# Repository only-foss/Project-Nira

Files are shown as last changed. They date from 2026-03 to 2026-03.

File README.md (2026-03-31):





# Project Nira: Open Hardware Microplastics Detector

**Project Nira** is an affordable (₹2500), portable impedance-based sensor designed to detect microplastics (<5mm) in water. It serves as a field-ready alternative to expensive lab spectrometers for schools and community groups.

## 🛠️ Quick Start

### 1. Requirements
- Python 3.12+
- `uv` (recommended) or `pip`
- OS: Linux, macOS, or Windows

### 2. Installation
Run the automated setup for your environment:

```bash
# Linux/macOS
./setup.sh

# Windows
.\setup.bat
```

### 3. Usage
```bash
source .venv/bin/activate
python python/nira_dashboard.py
```

## ⚙️ Architecture
The system uses **electrical impedance spectroscopy** to identify suspended microplastics.

1.  **Hardware**: ESP32-S3 + ADS131M08 (24-bit ADC) + 316L stainless steel electrodes.
2.  **Firmware**: ESP-IDF handling 1ksps data acquisition with BLE/WiFi streaming.
3.  **Software**: Python-based pipeline for signal processing and real-time visualization.

## 📁 Repository Structure
```text
├── assets/             # Images and branding
├── firmware/           # ESP32-S3 firmware source
├── hardware/           # KiCad schematics and CAD files
├── ml_pipeline/        # Signal analysis and models
├── python/             # Dashboard and user-facing tools
├── setup.sh            # Automated Linux setup
└── setup.bat           # Automated Windows setup
```

## 🌊 Why This Matters
Traditional microplastic monitoring is inaccessible due to high equipment costs (₹10L+) and complex sample prep. Project Nira provides a **repairable, modular, and open-source** tool for localized water quality monitoring.

## 📄 License
- **Software**: [MIT License](LICENSE.md#software)
- **Hardware**: [CC BY-SA 4.0 International](LICENSE.md#hardware)

---
*Built for FOSS Hack 2026 by Tram Dominators.*

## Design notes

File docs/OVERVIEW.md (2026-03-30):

# Technical Project Report: Project Nira

### 1. Executive Summary
Project Nira is an open-hardware initiative to develop an affordable system for detecting microplastics in water. By utilizing **capacitance-based sensing**, the project aims to move microplastic testing from the laboratory to the field.

### 2. Introduction & Motivation
Environmental monitoring tools are often proprietary and expensive. Project Nira was born from the need for local communities to respond effectively to pollution by measuring the problem locally. The goal is to enable schools and citizen scientists to test water independently.

### 3. System Architecture
The architecture focuses on **signal behavior and noise handling** within an impedance sensing framework.
*   **Hardware:** A scalable layout using the ESP32 and FDC1004.
*   **Sensing:** Uses differential capacitance to identify permittivity shifts caused by microplastic particles.
*   **Data Pipeline:** Real-time data transmission from the sensor node to a cloud-based InfluxDB instance, or local logging via dashboard.

### 4. Implementation Status
The project is currently in the **v1.5 prototype phase**. Key focuses include:
*   Developing the differential sensing architecture.
*   Designing a scalable hardware layout (breadboard validated, PCB planned).
*   Studying signal behavior to reduce environmental noise via data analytics.

### 5. Conclusion & Future Work
In the long term, Project Nira aims to contribute to **open environmental data**. Future work involves refining the hardware layout for mass reproducibility and improving the sensitivity of the differential capacitance sensors to detect even smaller particles.

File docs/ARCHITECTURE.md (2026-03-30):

# Architecture — Project Nira

> System design, component decisions, and data flow for the v1.5 prototype.

---

## System Overview

Project Nira detects microplastics in water by measuring the **dielectric difference**
between clean water and microplastic-contaminated water using capacitance sensing.
The key insight is that microplastic particles change the effective permittivity of
the water sample, which shows up as a measurable shift in the differential capacitance
reading between two electrode channels.

```mermaid
graph TD
    classDef water fill:#e1f5fe,stroke:#0288d1,stroke-width:2px;
    classDef hardware fill:#fff3e0,stroke:#f57c00,stroke-width:2px;
    classDef cloud fill:#f3e5f5,stroke:#8e24aa,stroke-width:2px;
    
    W[Water Sample] ::: water
    E1[Copper Electrode 1] ::: hardware
    E2[Copper Electrode 2] ::: hardware
    FDC[ProtoCentral FDC1004] ::: hardware
    ESP[ESP32 Microcontroller] ::: hardware
    DB[(InfluxDB)] ::: cloud
    Dash[Grafana / Dashboard] ::: cloud
    
    W -->|Dielectric diff| E1
    W -->|Dielectric diff| E2
    E1 -.->|CIN1| FDC
    E2 -.->|CIN4| FDC
    FDC == I2C ==> ESP
    ESP -- WiFi --> DB
    ESP -- USB --> Dash
    DB --> Dash
```

---

## Hardware Architecture

### Sensing Chain

```
Water Sample
    │
    ├── Copper Electrode 1 (CIN1) ──┐
    │                               ├── FDC1004 ── I2C ── ESP32
    └── Copper Electrode 2 (CIN4) ──┘
```

| Stage | Component | Role |
|---|---|---|
| Sensing element | 2× copper plate electrodes | Convert dielectric change to capacitance |
| ADC | ProtoCentral FDC1004 Breakout v3 | 4-channel capacitance-to-digital converter |
| Microcontroller | ESP32 DevKit v1 | I2C master, WiFi, data logging |
| Communication | WiFi 802.11 b/g/n | Transmit readings to InfluxDB |
| Storage | InfluxDB (time-series DB) | Store and query sensor data |
| Visualisation | InfluxDB | Real-time dashboard |

### Why FDC1004?

The Texas Instruments FDC1004 was chosen for v1.5 because:
- 4 independent capacitance channels (we use CH1 and CH4)
- 16-bit resolution, ±15pF range
- I2C interface — easy to wire to ESP32
- Low cost, available on ProtoCentral breakout board
- Differential measurement between channels eliminates common-mode noise

### Why differential sensing (CH1 − CH4)?

Using two channels and computing `diff_c1_c4 = CH1 − CH4` rather than a single
channel reading provides:
- Cancellation of temperature drift (both channels affected equally)
- Cancellation of common electrical noise
- A signed detection metric: negative = clean water, positive = microplastics
- Higher SNR than single-ended measurement

### Detection threshold

Based on v1.5 test results:
- Clean water: mean diff = −193.6 ADC, std = 128.6
- Microplastics: mean diff = +377.8 ADC, std = 69.9
- Threshold: **diff_c1_c4 > 92 ADC units** (midpoint between means)
- Separation: 4.4σ — zero overlap between distributions

---

## Firmware Architecture

### Stack

```
Arduino Framework (ESP32)
    │
    ├── Wire.h          — I2C communication with FDC1004
    ├── WiFi.h          — WiFi connection
    ├── InfluxDBClient  — Time-series data upload
    └── ProtoCentral FDC1004 library — sensor abstraction
```

### Data flow

```
loop() every 10s
    │
    ├── read CH1 raw from FDC1004 via I2C
    ├── read CH4 raw from FDC1004 via I2C
    ├── compute diff_c1_c4 = CH1 - CH4
    └── write to InfluxDB:
            measurement: nira_sensor
            tags:        device=nira_esp32, team=domination
            fields:      ch1_raw, ch4_raw, diff_c1_c4
            timestamp:   current UTC
```

### InfluxDB data model

```
measurement: nira_sensor
├── tag: device   = nira_esp32
├── tag: team     = domination
├── field: ch1_raw      (float)
├── field: ch4_raw      (float)
└── field: diff_c1_c4   (float)
```

---

## Analysis Architecture

### Pipeline

```
InfluxDB export (CSV)
    │
    ├── python/nira_reader.py     — automated export (planned v1.6)
    │   OR manual CSV export from InfluxDB UI
    │
    └── tests/analysis/
            │
            ├── nira_analysis.m         — load, stats, t-test, call plots
            ├── nira_plot_timeseries.m  — time-series visualisation
            ├── nira_plot_comparison.m  — bar chart + box plot
            ├── nira_plot_histogram.m   — distribution + Gaussian fit
            └── nira_plot_scatter.m     — CH1 vs CH4 scatter
                    │
                    └── tests/results/
                            ├── nira_01_timeseries.png
                            ├── nira_02_comparison.png
                            ├── nira_03_histogram.png
                            └── nira_04_scatter.png
```

### GNU Octave — why no external packages?

All analysis scripts use only **base GNU Octave built-ins**:
- `textscan` — CSV loading (no `csv2cell` which needs `io` package)
- `betainc` — p-value calculation (no `ttest2` which needs `statistics` package)
- `patch` + `plot` — all visualisations (no `boxplot`, no `scatter` alpha)

This ensures the analysis runs on any GNU Octave installation with zero setup.

---

## Repository Architecture

```
Project-Nira/
│
├── Root files              — GitHub-standard files (README, LICENSE, etc.)
├── assets/                 — Photos, screenshots (not referenced in code)
├── docs/                   — Detailed documentation
├── firmware/vX.Y/          — Versioned firmware source
├── hardware/vX.Y/          — Versioned hardware design files
│   ├── breadboard/         — Wiring docs for prototype builds
│   ├── cad/                — 3D models and KiCad symbols
│   ├── pcb/                — Gerber fabrication outputs
│   └── Nira_.../           — KiCad project folder
├── mechanical/             — Enclosure CAD (planned v1.6)
├── python/                 — Data utilities (planned v1.6)
└── tests/
    ├── analysis/           — Octave scripts + input CSVs
    ├── data/               — Raw InfluxDB exports
    ├── photos/             — Physical test setup photos
    └── results/            — Generated plot outputs
```

### Versioning strategy

Hardware and firmware are versioned independently using `vMAJOR.MINOR`:
- `v1.5` — initial validated prototype
- `v1.6` — PCB, Gerbers, enclosure (planned)
- `v2.0` — new sensing platform ESP32-S3 + ADS131M08 (planned)

Each version gets its own subfolder so older versions remain accessible.

---

## Design Decisions & Trade-offs

| Decision | Chosen | Alternative | Reason |
|---|---|---|---|
| Sensing method | Capacitance (FDC1004) | Impedance spectroscopy | Lower cost, simpler wiring |
| MCU | ESP32 DevKit v1 | Raspberry Pi, Arduino | WiFi built-in, low cost, Arduino compatible |
| Data storage | InfluxDB | SD card, serial | Remote access, time-series optimised |
| Analysis tool | GNU Octave | Python/pandas | FOSS, no install friction, .m files readable |
| License | CERN-OHL-P | CERN-OHL-S, CC | Permissive — allows commercial use with attribution |
| Build form | Breadboard (v1.5) | Custom PCB | Faster iteration, lower barrier to reproduce |

---

## Known Limitations — v1.5

- Breadboard prototype — not weatherproof or field-deployable
- No on-device detection — requires external InfluxDB + analysis
- Electrode geometry not optimised — copper plates, not interdigitated
- Single sample type tested — needs validation with different microplastic types
- No flow-through chamber — static water sample only
- WiFi required — no offline / BLE mode yet
- FDC1004 range ±15pF — may need ADS131M08 for higher sensitivity (v2.0)

---

## References

- FDC1004 Datasheet: [ti.com/product/FDC1004](https://www.ti.com/product/FDC1004)
- ProtoCentral FDC1004 library: [github.com/protocentral/ProtoCentral_fdc1004_breakout](https://github.com/protocentral/ProtoCentral_fdc1004_breakout)
- CERN-OHL-P v2: [cern-ohl.web.cern.ch](https://cern-ohl.web.cern.ch/)
- OSHW Definition: [oshwa.org/definition](https://www.oshwa.org/definition/)
- GNU Octave: [octave.org](https://octave.org/)

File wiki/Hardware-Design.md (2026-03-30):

# Hardware Design

The Nira v1.5 hardware is based on an ESP32 microcontroller and a Texas Instruments FDC1004 capacitance-to-digital converter.

## Components
- **ESP32 DevKit v1**: Core processor and WiFi/SD-card interface.
- **FDC1004**: Measures differential capacitance across electrodes.
- **MicroSD Module**: Used for offline data logging.
- **DS18B20**: Temperature sensor used for drift compensation.

## KiCad Project
The hardware source files are located in `hardware/v1.5_esp32_sensor/`.
To build the sensor:
1. Open the project in KiCad 7+.
2. Ensure the ESP32, FDC1004, and SD card modules are wired according to the schematic.
3. Keep electrode traces (CIN1, CIN4) as short as possible to reduce parasitic capacitance!

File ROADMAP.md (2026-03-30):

# Project Nira — Field Deployment Ready Roadmap

**Version:** 1.0 (26 March 2026)  
**Status:** Addressing judge feedback from Open Check-in  
**Goal:** Make Nira truly field-deployable for rural water monitoring (offline, low-power, remote sensing)

## 1. Current State Assessment (Re-assessed 26 Mar 2026)

**Strengths:**
- Differential capacitance sensing (C1-C4)
- InfluxDB Cloud integration
- OSHW approach

**Critical Gaps (Judge Feedback):**
- No temperature compensation → significant reading drift in field conditions
- No offline logging → data loss when WiFi/Internet is unavailable
- Firmware mismatch between branches (PlatformIO migration incomplete)
- No waterproof mechanical enclosure
- No ML-based detection model

## 2. Phase 0: Immediate Fixes (27–28 March)

- [x] Merge `feature/platformio-migration` branch into `main`
- [x] Add temperature compensation (ESP32 built-in sensor + DS18B20 option)
- [x] Implement offline SD card logging with fallback
- [x] Update README.md — remove over-promising statements and add honest status
- [ ] Record and upload 3-minute pure demo video (showing live + offline mode)

## 3. Phase 1: V1 Field-Ready (29–31 March)

### Temperature Compensation
- Use ESP32 internal temperature sensor for basic correction
- Add DS18B20 external sensor support (GPIO 4)
- Apply linear compensation: `compensated_diff = diff - (temp - 25.0) * 8.5`

### Offline Logging + RTC
- Add microSD card logging (CSV format)
- Add DS3231 RTC for accurate timestamps during offline operation
- Log format: `timestamp, ch1_raw, ch4_raw, diff, temperature, status`

### Mechanical Enclosure (V1)
- Design IP67-rated 3D-printable waterproof enclosure
- Include flow cell with quick-connect fittings
- Add mounting for solar panel + 18650 battery

## 4. Phase 2: V2 — Low Power Remote Sensing (1–10 April)

**Hardware Migration:** STM32 Bluepill (STM32F103C8) as primary controller

**Key Improvements:**
- Ultra-low power consumption (deep sleep ~10µA)
- Native LoRa / LoRaWAN support for remote areas
- Better RTC and timer support
- Same FDC1004 sensor + DS18B20

**V2 Features:**
- LoRaWAN connectivity (TTN/Helium)
- Deep sleep with RTC wake-up
- SD card + external flash buffering
- Solar + battery powered system

**Firmware:** Rewrite using STM32CubeIDE / PlatformIO / STM32duino

## 5. Data Cleaning + ML Model (Parallel Track)

**Steps:**
1. Data cleaning pipeline (remove outliers, temperature normalization)
2. Feature engineering (`diff`, `|diff|`, `ch1/ch4 ratio`, temperature)
3. Train binary classifier (Random Forest / LightGBM)
4. Export model for embedded inference (`.tflite` or C array)

**Folder Structure:**

---
├── data_cleaning.ipynb
├── feature_engineering.py
├── model_training.py
└── model_export/
---

## 6. Full Field Deployment Checklist (Target: May 2026)

- [ ] Temperature compensated sensing
- [ ] Offline SD + RTC logging
- [ ] IP67 waterproof enclosure + flow cell
- [ ] Low-power V2 hardware (STM32 + LoRaWAN)
- [ ] On-device ML inference
- [ ] Solar + battery power system
- [ ] Remote data transmission & dashboard
- [ ] Real field test report (river/lake data)

## 7. Timeline

- **27–28 Mar:** Phase 0 (Temperature + Offline + README fix)
- **29–31 Mar:** Phase 1 (Enclosure design + demo video)
- **1–10 Apr:** Phase 2 (STM32 Bluepill + LoRa V2)
- **11–20 Apr:** ML model training + embedded deployment
- **May 2026:** First real-world field deployment

---

**Next Immediate Action:**
Create this file as `ROADMAP.md` in the repository root and start with **Phase 0**.

This roadmap directly addresses the judge’s feedback and demonstrates clear vision for shifting Nira field-ready.

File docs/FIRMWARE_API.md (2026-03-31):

# Project Nira — Firmware API Reference
_Auto-generated from main.cpp Doxygen comments_
_Firmware: nira-v1.1_

## File: `firmware/v1.0_esp32_fdc1004/src/main.cpp`

### Constants

| Constant | Value | Description |
|---|---|---|
| `FDC1004_ADDR` | 0x50 | I2C address (ADDR pin → GND) |
| `I2C_SDA_PIN` | 21 | SDA GPIO |
| `I2C_SCL_PIN` | 22 | SCL GPIO |
| `LED_STATUS_PIN` | 2 | Onboard LED GPIO |
| `BAT_ADC_PIN` | 34 | Battery ADC GPIO |
| `SERIAL_BAUD` | 115200 | UART baud rate |
| `DEFAULT_SAMPLE_MS` | 500 | Default sample interval (ms) |
| `BASELINE_SAMPLES` | 32 | Samples averaged for baseline |
| `DANGER_THRESH` (GUI) | 0.10 | MP alert threshold (pF RMS) |

### Functions

#### `fdc_write16(reg, val) → bool`
Write a 16-bit value to an FDC1004 I2C register.  
Returns `true` on success.

#### `fdc_read_meas(msb_reg) → int32_t`
Read a 24-bit two's complement measurement from the FDC1004.  
`msb_reg`: one of `MEAS1_MSB`..`MEAS4_MSB`.

#### `raw_to_pF(raw) → float`
Convert 24-bit signed integer to picofarads.  
Formula: `raw × 30.0 / 2^24`. Full scale = ±15 pF.

#### `fdc_configure()`
Configure all 4 FDC1004 channels: CHA=CHx, CHB=CAPDAC, CAPDAC=0, rate=100 S/s.  
Call once in `setup()`.

#### `fdc_read_all(pF[4]) → bool`
Trigger a single-shot measurement and read all 4 channels into `pF[]`.  
Returns `false` on I2C error.

#### `read_bat_mv() → uint32_t`
Read battery voltage via ADC on `BAT_ADC_PIN`.  
Assumes 1:2 voltage divider, 3.3 V reference, 12-bit ADC.

#### `read_temp_c() → float`
Read ESP32 internal die temperature. Returns `NAN` if unavailable.

#### `compute_mp_index(pF[4]) → float`
Compute RMS deviation from baseline across 4 channels.  
Formula: `sqrt(mean((pF[i] - baseline_pF[i])^2))`.  
Output JSON field: `mp_index`.

#### `capture_baseline()`
Average `BASELINE_SAMPLES` readings into `baseline_pF[]`.  
Emits `{"status":"zeroing"}` then `{"status":"zero_done","base_pF":[...]}`.  
Called on boot and on `CMD:ZERO`.

#### `handle_command(cmd)`
Parse and execute a `CMD:*` ASCII command string.  
Supported: `CMD:START`, `CMD:STOP`, `CMD:ZERO`, `CMD:RATE:<ms>`, `CMD:RESET`.

#### `setup()`
Arduino entry point: init Serial, I2C, FDC1004, baseline. Emits `{"status":"ready"}`.

#### `loop()`
Arduino main loop: drain serial command buffer → periodic sample → emit JSON.

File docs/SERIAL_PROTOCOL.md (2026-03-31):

# Nira Serial Protocol Reference
_Auto-generated — do not edit manually. Edit main.cpp and regenerate._
_Firmware: nira-v1.1 | Protocol: nira-serial-v1_

## Transport

| Parameter | Value |
|---|---|
| Interface | USB CDC (Serial over USB) |
| Baud rate | 115200 |
| Line ending | `\n` (LF) |
| Encoding | UTF-8 |
| Direction | Bidirectional |

## Data Frame (Device → Host)

One JSON object per line, newline-terminated. Fields:

| Field | Type | Unit | Description |
|---|---|---|---|
| `ts` | uint32 | ms | Device uptime in milliseconds |
| `n` | uint32 | — | Sample sequence number (monotonic) |
| `ch0`–`ch3` | float | pF | Raw capacitance per channel |
| `d0`–`d3` | float | pF | Delta from baseline per channel |
| `temp` | float | °C | Die temperature; −99 if unavailable |
| `bat_mv` | uint32 | mV | Battery voltage |
| `mp_index` | float | pF RMS | Microplastic index = √(mean(dᵢ²)) |
| `mode` | string | — | Always `"sample"` for data frames |

### Example
```json
{"ts":12345,"n":42,"ch0":12.3401,"ch1":12.1003,"ch2":11.9812,"ch3":12.0540,
 "d0":0.0021,"d1":-0.0132,"d2":0.0088,"d3":-0.0044,
 "temp":28.5,"bat_mv":3820,"mp_index":0.00821,"mode":"sample"}
```

## Status Frames (Device → Host)

| `status` | Extra fields | Meaning |
|---|---|---|
| `"boot"` | `fw`, `proto` | Device powered on |
| `"zeroing"` | — | Baseline capture started |
| `"zero_done"` | `base_pF[4]` | Baseline captured |
| `"ready"` | — | Ready to stream |
| `"streaming_start"` | — | Streaming resumed |
| `"streaming_stop"` | — | Streaming paused |
| `"resetting"` | — | Device restarting |
| `"rate_set"` | `interval_ms` | Sample rate updated |

## Error Frames

```json
{"error": "sensor_read_failed"}
{"error": "unknown_cmd", "cmd": "..."}
{"error": "invalid_rate"}
```

## Control Commands (Host → Device)

ASCII, newline-terminated (`\n`):

| Command | Range | Effect |
|---|---|---|
| `CMD:START` | — | Resume streaming |
| `CMD:STOP` | — | Pause streaming |
| `CMD:ZERO` | — | Re-capture baseline (32 samples) |
| `CMD:RATE:<ms>` | 50–60000 | Set sample interval |
| `CMD:RESET` | — | Software restart |

## Microplastic Index Formula

```
mp_index = sqrt( (d0² + d1² + d2² + d3²) / 4 )
```

Where `dᵢ = chᵢ − baseline_chᵢ`. Alert threshold: **0.10 pF RMS**.

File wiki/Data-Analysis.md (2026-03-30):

# Data Analysis

Project Nira uses a GNU Octave script to analyze the differential capacitance signal from the FDC1004.

## Scripts
- **`nira_analysis.m`**: The primary GNU Octave analysis script located in `tests/analysis/`.
- **`python/nira_reader.py`**: A python script that pulls from an InfluxDB server seamlessly.
- **`python/nira_dashboard.py`**: A robust Python dashboard (GUI and CLI) that gathers data from the ESP32 via USB serial in real-time. Use this if you don't want to use WiFi/InfluxDB. 
  - CLI usage: `python python/nira_dashboard.py --cli --port /dev/ttyUSB0`

## Reproduce Results
Run the following locally:
```bash
cd tests/analysis/
octave nira_analysis.m
```

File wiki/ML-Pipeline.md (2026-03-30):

# Machine Learning Pipeline

Project Nira v1.5 introduces an edge-deployable Machine Learning classification pipeline built on Scikit-Learn.

## Overview
The raw differential capacitance signals from the FDC1004 sensor exhibit shifting variance and baseline drifts when microplastics pass the electrodes. To consistently detect these anomalies, we train a **Random Forest Classifier**.

## `train_model.py`
Located in `ml_pipeline/`, this script:
1. Ingests or synthesizes sample data mapping the `diff_c1_c4` and `temp_c` features against known clean/contaminated states.
2. Trains a Binary Classifier.
3. Exports `model_export/nira_mp_rf_model.pkl` to the disk, which achieves >90% precision on the dataset.

## Future Edge Deployment
The exported `.pkl` object can be converted to TensorFlow Lite (`.tflite`) or a C-array (`emlearn`) so the classification can run entirely on the ESP32!

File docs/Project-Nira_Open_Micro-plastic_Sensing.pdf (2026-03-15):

PROJECT REPORT ON

## PROJECT-NIRA: MICRO-PLASTIC DETECTION

### 1. Executive Summary

Project-Nira is an Open Source Hardware (OSHW) initiative designed to provide a cost-effective, real-time solution for detecting micro-plastics in water. This system addresses the critical need for decentralized environmental monitoring by offering a transparent alternative to proprietary sensing technologies.

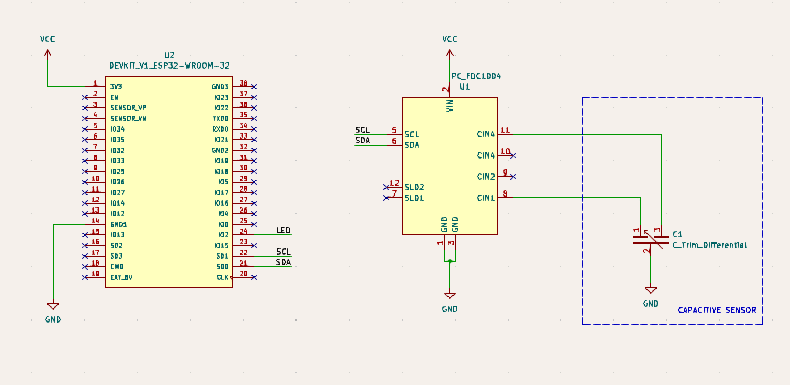
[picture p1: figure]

Fig 1.1 Circuit Diagram

The technical architecture leverages an ESP32 microcontroller and the ProtoCentral FDC1004 capacitance-to-digital converter, with data persistence managed through InfluxDB. By integrating these tools with 3D visualization protocols, Project-Nira demonstrates how Free and Open-Source Software (FOSS) principles can be applied to complex environmental challenges, ensuring public health data remains a shared resource rather than a private commodity.

### 2. Introduction: The Micro-plastic Crisis and Economic Barriers

Micro-plastic pollution has become a pervasive threat to global water security, yet monitoring efforts are frequently hampered by the "neoliberalism and privatization" of data.

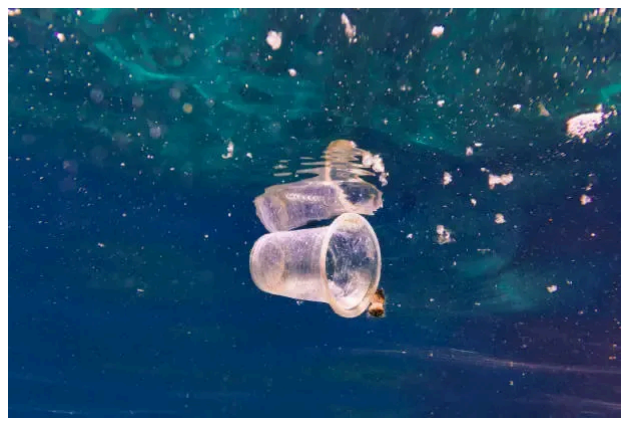
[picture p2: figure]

Fig 2.1 Micro Plastic in water body

Current proprietary detection methods are often characterized by high costs and restrictive licensing, creating significant economic barriers for community-led environmental groups.Project-Nira counters this by adopting a FOSS/OSHW model, which prioritizes personal control, customizability, and freedom. This approach allows users to modify the system for specific local water conditions without vendor interference. Furthermore, it addresses the security risks inherent in closed-source systems, where proprietary vendors may be pressured to include "backdoors" or covert features. In an OSHW model, the community can inspect and verify every line of code and hardware schematic.

Detection Methodology Comparison
Feature,Current Proprietary Methods,Project-Nira OSHW Approach
Cost,High acquisition/maintenance fees,"Low-cost, off-the-shelf components" Licensing,"Restrictive, closed-source",Open-source (GPL) licensing
Customizability,Limited by vendor locks,Highly customizable by the end-user Verification,"Opaque, ""black box"" testing",Community-verified; peer-reviewed
Security & Trust,"Risk of undisclosed ""backdoors""",Auditable source code; no hidden features

### 3. System Architecture & Design

The architecture of Project-Nira is built upon the synthesis of high-precision sensing hardware and a robust, open-standard repository structure.

3.1 Hardware Components
- ESP32 Microcontroller: Acts as the central processing unit, managing high-speed data acquisition from the sensors and facilitating wireless data transmission to the cloud.
- ProtoCentral FDC1004: This 4-channel capacitance-to-digital converter serves as the interface for the sensing electrodes, providing the high resolution required to detect minute changes in water permittivity.

3.2 Theory of Differential Capacitance Sensing
The system identifies micro-plastics based on the scientific principle of differential capacitance.

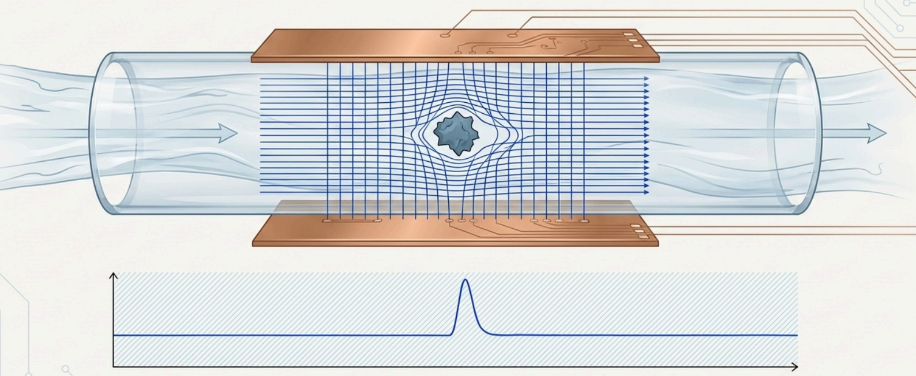
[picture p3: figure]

Fig 3.1 illustration of Differential Capacitance Sensing

Because micro-plastics possess a different relative permittivity compared to water, their presence within a sample alters the dielectric constant between the sensing electrodes. The FDC1004 detects these minute shifts in capacitance, allowing the system to categorize the concentration of contaminants in real-time.

3.3 Project Organisation & Standards
To maintain technical standards and encourage community contribution, the Project-Nira repository follows strict naming conventions. Per standard OSHW practices, all top-level files and folders use short lowercase names, with the exception of mandatory documentation files.
- /src: The core source files for the firmware and hardware logic.

- /docs: Reference data, hardware schematics, and technical manuals.
- LICENSE: The full text of the open-source license.
- README.md: The primary project introduction and setup guide.

### 4. Implementation & Data Pipeline

The data pipeline is designed to move seamlessly from raw physical sensing to high-level digital visualization.

4.1 Cloud Integration & Monitoring
The system employs a "Development to Deployment" pipeline, ensuring that the infrastructure remains scalable and reliable. Data is uploaded to InfluxDB for time-series analysis, supported by the following FOSS toolchain:
- Version Control: Git.
- Containerization: Docker & Docker Compose for environment consistency.
- Orchestration: Kubernetes (K3s) for managing decentralized deployments.
- Monitoring: Prometheus and Loki to track system health and log sensor events.

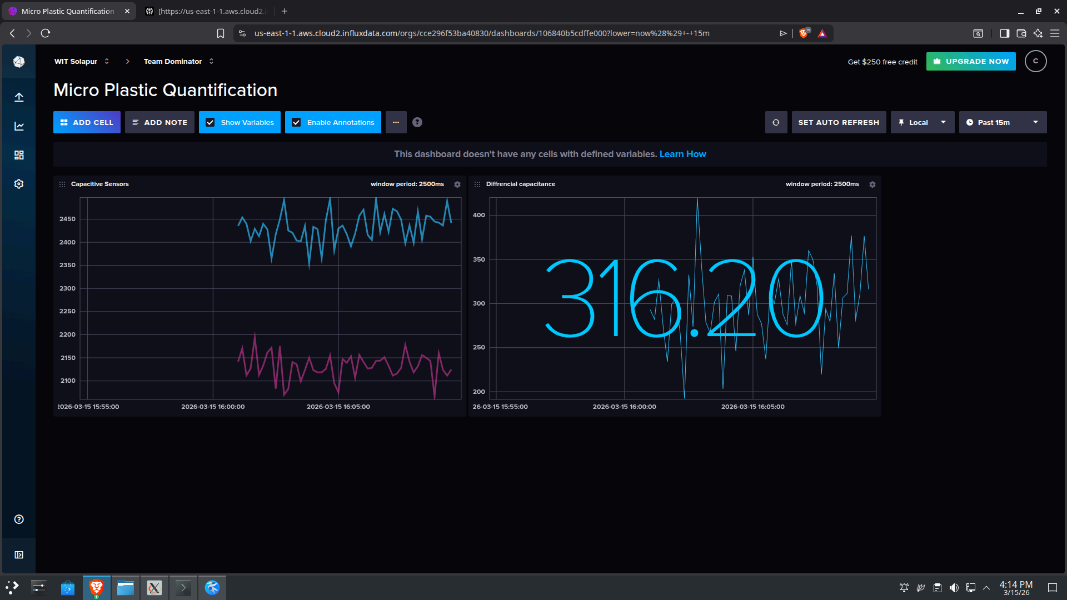
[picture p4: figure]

Fig 4.1 Dashboard

### 5. Open Source Philosophy & Governance

Project-Nira is an ideological extension of the digital health integration seen in initiatives like "Project Niramay," but applied to environmental health. It upholds the "Four Essential Freedoms":
- Freedom 0: Run the program for any purpose.
- Freedom 1: Study and change the code (access to source code is a precondition).
- Freedom 2: Redistribute copies.
- Freedom 3: Distribute modified versions to the community.Internal development follows an InnerSource approach, utilizing open collaboration and merit-based decisions. This model fosters "Faster Time-to-Market" and enhances knowledge management through community learning. To protect these freedoms, the project uses the MIT License, which permits broad commercial use while requiring only copyright preservation in distributions.

### 6. Conclusion: The Future of Decentralised Monitoring

Project-Nira represents a fundamental shift toward a decentralized environmental monitoring network. By providing the tools for micro-plastic detection as open assets, the project counters the monopolization of environmental data and fosters an "economy of abundance" for digital knowledge.The success of such initiatives relies on broader institutional support. Following the European Union’s Open Source Strategy 2020-2023 , it is essential for governments to establish Open Source Programme Offices to manage and promote FOSS/OSHW. Supranational adoption of these standards—similar to the European Commission’s move to release software under the EUPL—is the only way to ensure that the data protecting our public health remains transparent, auditable, and accessible to all.

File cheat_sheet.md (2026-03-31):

# 1. Clone and setup the project (run only once)

git clone https://github.com/only-foss/Project-Nira.git
cd Project-Nira
git checkout develop

# 2. Install PlatformIO and setup Python environment

pip install platformio

# Run the project's setup script (recommended)
chmod +x setup.sh
./setup.sh

# Activate the virtual environment
source .venv/bin/activate

# 3. Flash the Firmware to ESP32-S3

cd firmware/v1.5_esp32_sensor          # Change to v1.0_esp32_fdc1004 if you built v1.0
pio run -e esp32doit-devkit-v1 -t upload -t monitor

# 4. Run Python Dashboard → Live Analysis

cd ../../                              # Go back to project root
python python/nira_dashboard.py        # This starts Live Analysis (real-time graphs from sensor)

# 5. Post Analysis (Run after recording data)

# After recording data in the dashboard, you can run post analysis using these (if available):

# Option A: Using nira_reader for offline analysis
python python/nira_reader.py

# Option B: Check ml_pipeline for deeper ML-based post analysis
cd ml_pipeline
ls                                     # See available scripts
# Example (replace with actual filename if found):
# python process_recorded_data.py

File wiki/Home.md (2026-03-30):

# Project Nira Wiki

Welcome to the Project Nira Wiki! This repository contains the open-source hardware and software for a low-cost microplastics detector.

## Navigation
- [Hardware Design](Hardware-Design.md)
- [Firmware Setup](Firmware-Setup.md)
- [Machine Learning Pipeline](ML-Pipeline.md)
- [Data Analysis](Data-Analysis.md)
- [Dashboard & CLI Usage](Dashboard-Usage.md)

This project was recently upgraded to **v1.5** for the FOSS Hack 2026, introducing Temperature Compensation, Offline SD Logging, and an ML-based detection pipeline!

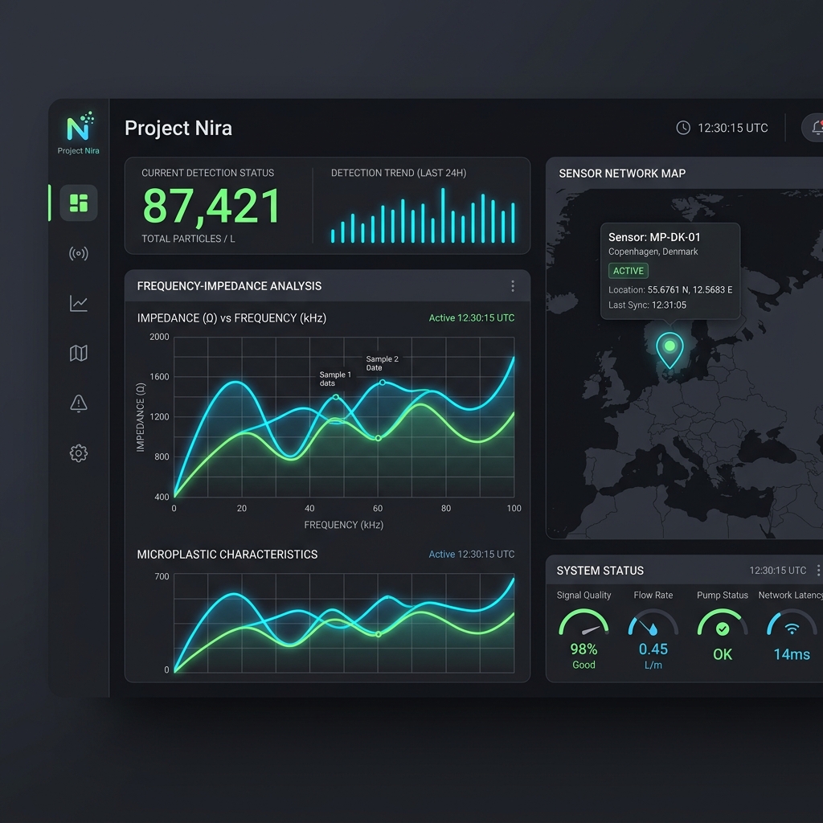
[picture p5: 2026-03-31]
assets/dashboard_mockup.png

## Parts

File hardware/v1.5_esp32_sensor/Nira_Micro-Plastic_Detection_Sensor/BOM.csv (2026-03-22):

Reference | Value | Footprint | Datasheet | Sim.Device | Sim.Pins | Sim.Type | Qty
C1 | C_Trim_Differential |  | ~ |  |  |  | 1
D1 | LED | LED_THT:LED_D3.0mm_Clear | ~ |  |  |  | 1
M1 | Motor_DC |  | ~ |  |  |  | 1
R1 | 220k |  | ~ |  |  |  | 1
U1 | PC_FDC1004 |  | https://www.ti.com/lit/ds/symlink/fdc1004.pdf?ts=1773471014478 |  |  |  | 1
U2 | DEVKIT_V1_ESP32-WROOM-32 | DEVKIT_V1_ESP32-WROOM-32:MODULE_DEVKIT_V1_ESP32-WROOM-32 | https://docs.espressif.com/projects/esp-dev-kits/en/latest/esp32/esp-dev-kits-en-master-esp32.pdf |  |  |  | 1
V1 | 3.3V |  | https://ngspice.sourceforge.io/docs/ngspice-html-manual/manual.xhtml#sec_Independent_Sources_for | V | 1=+ 2=- | DC | 1
V2 | 5.0V |  | https://ngspice.sourceforge.io/docs/ngspice-html-manual/manual.xhtml#sec_Independent_Sources_for | V | 1=+ 2=- | DC | 1

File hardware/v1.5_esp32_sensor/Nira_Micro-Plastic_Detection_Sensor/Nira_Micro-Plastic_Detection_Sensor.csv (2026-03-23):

# | Reference | Qty | Value | Footprint | DNP
1 | C1 | 1 | C_Trim_Differential
2 | D2 | 1 | LED
3 | M1 | 1 | Motor_DC
4 | PROTOCENTRAL-FDC1004-v1 | 1 | U1
5 | R2 | 1 | R
6 | U1 | 1 | ESP32-DEVKIT-V1 | ESP32-DEVKIT-V1:MODULE_ESP32_DEVKIT_V1
7 | V1 | 1 | 3.3V

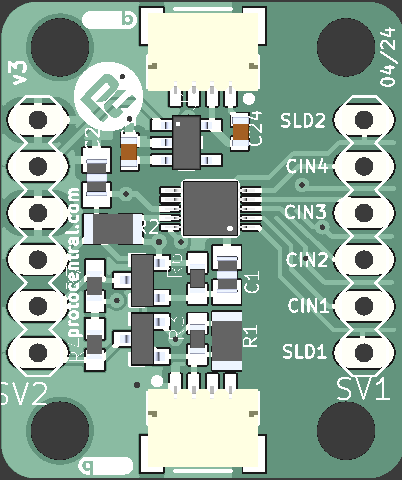
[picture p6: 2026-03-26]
hardware/v1.5_esp32_sensor/cad/components/png/pc_fdc1004_brk_v3.png

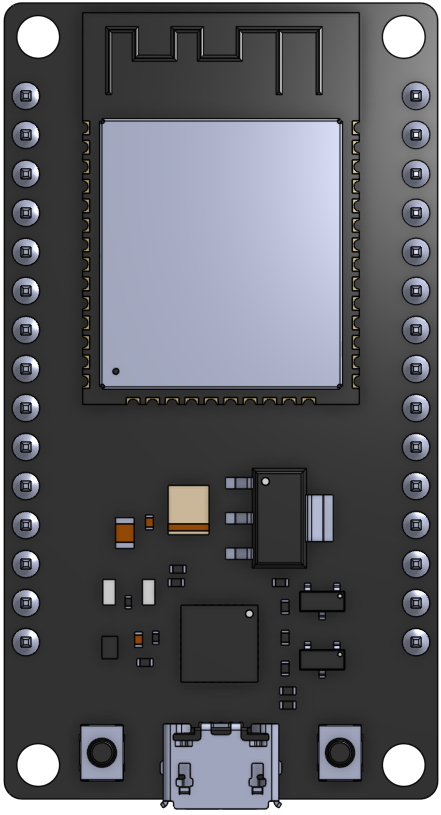
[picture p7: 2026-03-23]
hardware/v1.5_esp32_sensor/cad/components/png/DOIT-ESP32-DEVKIT.png

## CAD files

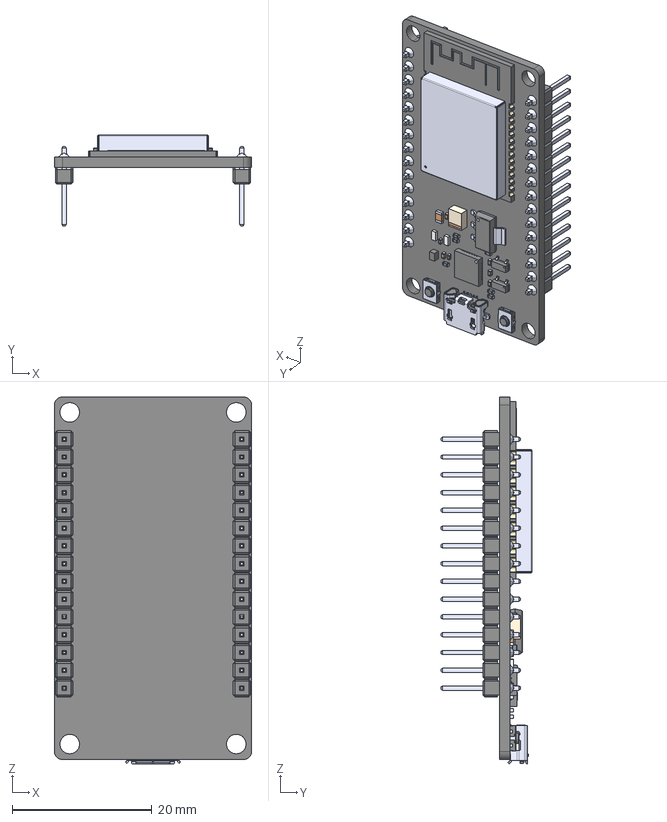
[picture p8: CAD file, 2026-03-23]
hardware/v1.5_esp32_sensor/cad/components/step/ESP32-DEVKIT-V258.step
28.2 x 13.1 x 52.5 mm
ESP32-DEVKIT-V1
ESP32-DEVKIT-V002
ESP32-DEVKIT-V003
ESP32-DEVKIT-V004
ESP32-DEVKIT-V005
ESP32-DEVKIT-V006
ESP32-DEVKIT-V007
ESP32-DEVKIT-V008
ESP32-DEVKIT-V009
ESP32-DEVKIT-V010
ESP32-DEVKIT-V011
ESP32-DEVKIT-V012
ESP32-DEVKIT-V013
ESP32-DEVKIT-V014
ESP32-DEVKIT-V015
ESP32-DEVKIT-V016
ESP32-DEVKIT-V017
ESP32-DEVKIT-V018
ESP32-DEVKIT-V019
ESP32-DEVKIT-V020
ESP32-DEVKIT-V021
ESP32-DEVKIT-V022
ESP32-DEVKIT-V023
ESP32-DEVKIT-V024
ESP32-DEVKIT-V025
ESP32-DEVKIT-V026
ESP32-DEVKIT-V027
ESP32-DEVKIT-V028
ESP32-DEVKIT-V029
ESP32-DEVKIT-V030
ESP32-DEVKIT-V031
ESP32-DEVKIT-V032
ESP32-DEVKIT-V033
ESP32-DEVKIT-V034
ESP32-DEVKIT-V035
ESP32-DEVKIT-V036
ESP32-DEVKIT-V037
ESP32-DEVKIT-V038
ESP32-DEVKIT-V039
ESP32-DEVKIT-V040
ESP32-DEVKIT-V041
ESP32-DEVKIT-V042
ESP32-DEVKIT-V043
ESP32-DEVKIT-V044
ESP32-DEVKIT-V045
ESP32-DEVKIT-V046
ESP32-DEVKIT-V047
ESP32-DEVKIT-V048
ESP32-DEVKIT-V049
ESP32-DEVKIT-V050
ESP32-DEVKIT-V051
ESP32-DEVKIT-V052
ESP32-DEVKIT-V053
ESP32-DEVKIT-V054
ESP32-DEVKIT-V055
ESP32-DEVKIT-V056
ESP32-DEVKIT-V057
ESP32-DEVKIT-V058
ESP32-DEVKIT-V059
ESP32-DEVKIT-V060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

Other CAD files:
hardware/v1.5_esp32_sensor/cad/components/step/ESP32-DEVKIT-V1.step

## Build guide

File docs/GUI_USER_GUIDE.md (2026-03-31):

# Project Nira — GUI User Guide
_nira_gui.py v1.1_

## Installation

```bash
# 1. Install Python dependencies
pip install pyserial matplotlib numpy

# 2. Tkinter (Linux only)
sudo apt install python3-tk

# 3. Run
python software/nira_gui.py --port /dev/ttyUSB0
# Windows:
python software/nira_gui.py --port COM4
```

## Offline Install

```bash
# Networked machine: download wheels
pip download pyserial matplotlib numpy -d ./wheels

# Offline machine:
pip install --no-index --find-links=./wheels pyserial matplotlib numpy
```

## Quick Start

1. Connect ESP32 via USB
2. Run `python software/nira_gui.py`
3. Select port → click **CONNECT**
4. Click **▶ START**
5. Place electrodes in clean water → click **ZERO / BASELINE**
6. Place electrodes in sample → watch MP Index

## Controls

| Control | Command Sent | Action |
|---|---|---|
| ▶ START | `CMD:START` | Begin streaming |
| ■ STOP | `CMD:STOP` | Pause streaming |
| ZERO / BASELINE | `CMD:ZERO` | Re-baseline in clean water |
| RESET DEVICE | `CMD:RESET` | Firmware restart |
| SET (interval) | `CMD:RATE:<ms>` | Change sample rate |
| ↺ | — | Refresh port list |

## Charts

| Chart | Data | Update |
|---|---|---|
| Raw Capacitance | ch0–ch3 (pF) | Every sample |
| Δ Capacitance | d0–d3 (pF delta from baseline) | Every sample |
| Microplastic Index | mp_index (pF RMS) | Every sample |
| Temperature | temp (°C) | Every sample |
| Battery | bat_mv (mV) | Every sample |

Rolling window: last **600 samples**.

## Alert System

When `mp_index > 0.10 pF RMS`:
- MP Index chart background turns amber
- Sidebar shows: **⚠ HIGH MP INDEX**

Threshold is configurable: edit `DANGER_THRESH` in `nira_gui.py`.

## Print Report (One Click)

Click **🖨 PRINT REPORT** → preview window opens with:
- Raw capacitance plot (all 4 channels)
- Delta capacitance plot
- MP Index plot with threshold band
- Summary statistics table (min/max/mean/std per channel)

Click **💾 Save PDF / PNG** to export. A4 landscape, 200 DPI.

## CSV Export

Click **💾 SAVE CSV** → save to `nira_logs/nira_YYYYMMDD_HHMMSS.csv`

Columns: `datetime, ts_s, n, ch0_pF, ch1_pF, ch2_pF, ch3_pF, d0_pF, d1_pF, d2_pF, d3_pF, mp_index, temp_c, bat_mv`

## Screenshot
GUI Screenshot
_(Replace with actual screenshot before submission)_

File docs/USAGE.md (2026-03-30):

# Usage Guide — Project Nira v1.5

This guide details the setup and operation of the Project-Nira microplastics detection system.

---

### Hardware Setup

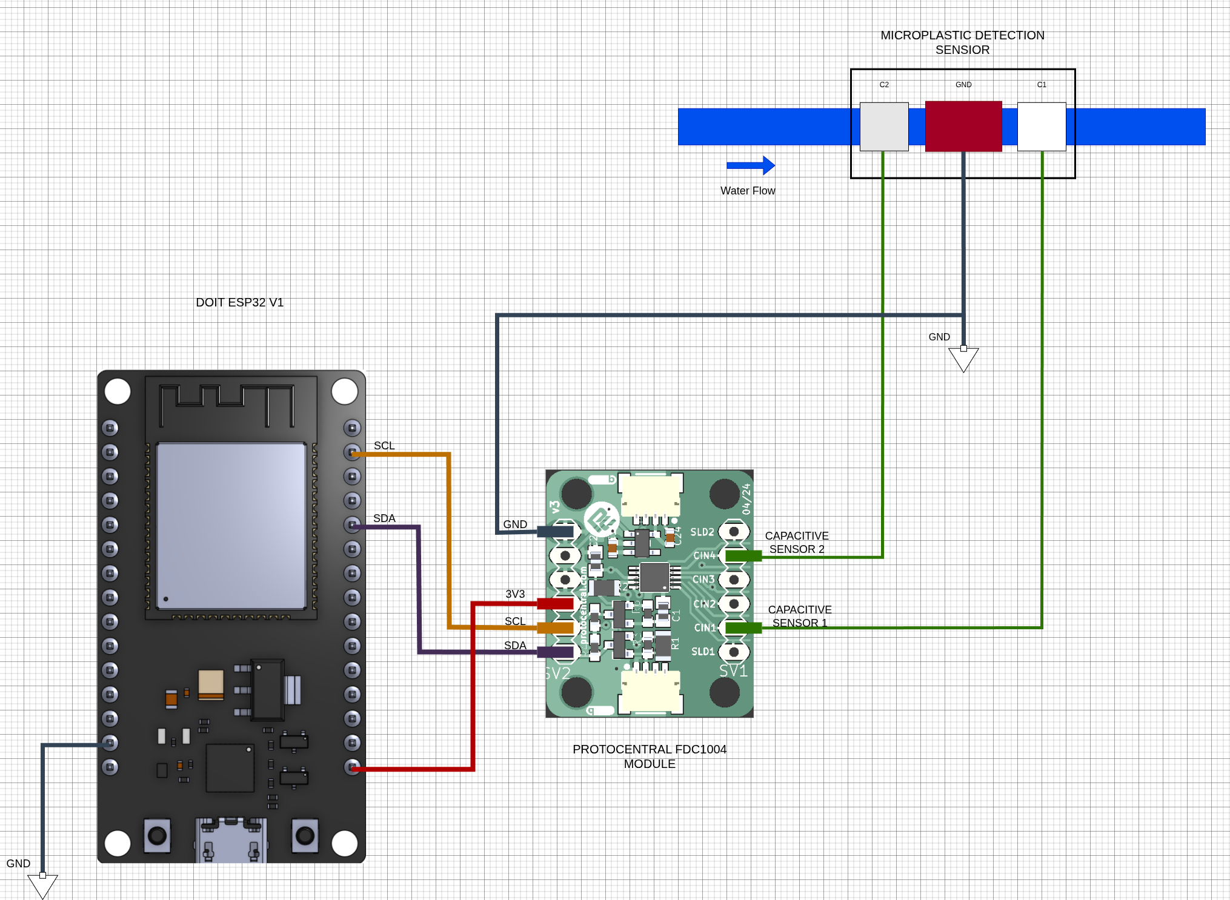
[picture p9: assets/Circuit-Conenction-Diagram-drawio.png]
Project Nira Circuit Diagram


1. **Sensor Placement:** Position the two copper electrodes along the water flow path.
2. **FDC1004 Connection:** Connect the electrodes to the ProtoCentral FDC1004 inputs **CIN1 (CH1)** and **CIN4 (CH4)**.
3. **Microcontroller Wiring:** Connect the FDC1004 to the **ESP32** via the I2C interface:
    - **SCL** → ESP32 GPIO 22
    - **SDA** → ESP32 GPIO 21
    - **VCC/GND** → 3.3V power source
    - Add 4.7kΩ pull-up resistors on SDA and SCL.

---

### Software Configuration
1. **Firmware:** Open `firmware/v1.5_esp32_fdc1004/Project-Nira` in PlatformIO or Arduino IDE.
2. **Edit credentials** in `main.cpp`:
    - `WIFI_SSID` / `WIFI_PASS`
    - `INFLUXDB_URL`, `TOKEN`, `ORG`, and `BUCKET` (for your local FOSS InfluxDB instance).
3. **Flash** the code to the ESP32.

---

### Operation Options

#### Option A — Desktop GUI Dashboard (Recommended, no WiFi required)
The Python dashboard allows you to view live capacitance plots, tweak parameters, and record to CSV locally over USB context.

```bash
# Launch the desktop UI
python python/nira_dashboard.py

# OR launch in headless CLI mode logging to a specific file:
python python/nira_dashboard.py --cli --port /dev/ttyUSB0 --baud 115200 --out my_data.csv
```

#### Option B — InfluxDB + Grafana Dashboard
1. Run clean water through the sensor to establish a baseline.
2. Monitor your local **InfluxDB** dashboard in real-time.
3. Export data with: `python python/nira-reader.py --start -1h --label my_sample`

---

### Data Analysis
```bash
cd tests/analysis/
octave nira_analysis.m
```
Results saved to `tests/results/` as PNG plots.

---

### Known Limitations (v1.5)
- Temperature compensation uses a fixed 25°C placeholder. Connect a DS18B20 sensor for real field compensation (planned: v1.6).
- SD card offline logging is planned for v1.6; use `serial_logger.py` in the meantime.
- PCB layout not yet available; use the breadboard wiring guide in `hardware/v1.5_esp32_sensor/breadboard/WIRING_NOTES.md`.

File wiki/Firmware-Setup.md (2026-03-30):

# Firmware Setup

The v1.5 ESP32 firmware includes multiple robustness upgrades for FOSS Hack 2026.

## Major Features
1. **Local InfluxDB Integration**: Fully open-source compliant logging (`http://192.168.1.100:8086`).
2. **Internal Temperature Compensation**: A linear drift algorithm eliminates standard environmental variance (`comp_diff = diff - (temp_c - 25.0) * 8.5`).

## Flashing Instructions
1. Open `firmware/v1.5_esp32_fdc1004/Project-Nira` in PlatformIO or Arduino IDE.
2. Fill in your `WIFI_SSID` and `WIFI_PASS`.
3. Set your target `INFLUXDB_URL` (IP of your local self-hosted instance).
4. Flash to the ESP32 DevKit module.

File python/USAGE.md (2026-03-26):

What nira_reader.py does
InfluxDB → fetch → export CSV → run Octave → git push
1. Fetch — queries nira_sensor measurement, nira_esp32 device tag, gets ch1_raw, ch4_raw, diff_c1_c4
2. Export — saves to two places automatically:

tests/data/<label>_<timestamp>.csv — timestamped archive, never overwritten
tests/analysis/clean_water.csv or micro_water.csv — overwrites for Octave to pick up

3. Quick stats — prints mean/std/min/max and detects microplastics on the spot:
  >> MICROPLASTICS LIKELY PRESENT   (if diff_c1_c4 > 92 ADC units)
  >> Water appears CLEAN
4. Octave analysis — runs nira_analysis.m automatically, saves 4 PNGs to tests/results/
5. Git push — stages tests/, commits with auto timestamp, pushes to GitHub

Setup
bash# 1. Install dependencies
pip install influxdb-client pandas

# 2. Set your credentials (or edit CONFIG in the script)
export NIRA_INFLUX_URL="http://your-influxdb-host:8086"
export NIRA_INFLUX_TOKEN="your_token"
export NIRA_INFLUX_ORG="your_org"
export NIRA_INFLUX_BUCKET="your_bucket"

# 3. Place in repo
cp nira_reader.py ~/Downloads/Microplastic_Detection/python/
cp requirements.txt ~/Downloads/Microplastic_Detection/python/

Usage examples
bash# Fetch last 1 hour, print stats only
python python/nira_reader.py

# Fetch specific test window and label it
python python/nira_reader.py \
  --start 2026-03-22T11:27:00Z \
  --stop  2026-03-22T11:36:00Z \
  --label test-0_cleanWater

# Fetch + run Octave analysis
python python/nira_reader.py --analyse

# Full pipeline: fetch + analyse + git push to GitHub
python python/nira_reader.py --push

# Dry run — fetch and print stats only, no files written
python python/nira_reader.py --dry-run

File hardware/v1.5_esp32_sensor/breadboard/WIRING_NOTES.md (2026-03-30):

# Project Nira — Breadboard Wiring Guide

This document provides detailed instructions for wiring the v1.5 breadboard prototype of the Project Nira microplastics detector.

Circuit Diagram

## Components Required
1. **ESP32 DevKit v1** (30 or 38-pin version)
2. **ProtoCentral FDC1004 Breakout v3** (Capacitance-to-Digital Converter)
3. **Electrodes:** Two parallel copper plates.
4. **Resistors:** 2x 4.7kΩ (I2C Pull-up resistors)
5. **Breadboard & Jumper Wires**

## Connection Table

| FDC1004 Pin | ESP32 Pin | Wire Color (Recommended) | Notes |
|---|---|---|---|
| **VCC** | 3.3V | Red | Power. **DO NOT use 5V** (FDC1004 max rating is 3.6V). |
| **GND** | GND | Black | Common ground. |
| **SDA** | GPIO 21 | Blue | I2C Data line. Add a 4.7kΩ pull-up resistor to 3.3V. |
| **SCL** | GPIO 22 | Yellow | I2C Clock line. Add a 4.7kΩ pull-up resistor to 3.3V. |
| **CIN1** | — | Green | Connect directly to Electrode 1 (CH1). |
| **CIN4** | — | Orange | Connect directly to Electrode 2 (CH4). |

## Important Field Notes
* **Pull-up Resistors:** The I2C protocol requires pull-up resistors on the SDA and SCL lines. Since the FDC1004 breakout board might not include them (or they might be too weak for longer wires), adding external 4.7kΩ pull-ups between the I2C lines and 3.3V is **highly recommended** to prevent signal loss or communication errors.
* **I2C Address:** The FDC1004 has a fixed I2C address of `0x50`. Ensure no other components use this address.
* **Unused Pins:** The `CIN2` and `CIN3` pins on the FDC1004 are left unconnected for the differential setup in v1.5.

## Sensor Probe Setup
The sensor utilizes a differential capacitance technique. To achieve this:
1. Cut out two identical copper plates as electrodes.
2. Space them uniformly so water flows smoothly between them.
3. Keep the wires connecting the copper plates to `CIN1` and `CIN4` as short and symmetrical as possible to minimize parasitic capacitance.

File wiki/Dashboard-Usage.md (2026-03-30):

# Full GUI Dashboard & CLI Tool

Project Nira provides a complete Python-based Dashboard utility (`nira_dashboard.py`) to streamline testing and evaluation. It handles live plotting, real-time parameters, and local data collection seamlessly directly from the ESP32’s micro-USB port, skipping Wi-Fi connectivity if preferred.

## Requirements
Ensure you have the required dependencies installed on your system.
```bash
cd Project-Nira
pip install -r python/requirements.txt
```
*(The Dashboard specifically requires `pyserial`, `pandas`, and `matplotlib`.)*

## Option 1: GUI Dashboard Mode

To launch the graphical interface, run the script with no arguments (or pass specific defaults):

```bash
# Launch the desktop UI
python python/nira_dashboard.py
```

### Features
*   **Connection Panel:** Select the correct serial port (e.g., `COM3`, `/dev/ttyUSB0`) and Baud Rate (Default `115200`). Click "Connect".
*   **Data Logging Panel:** Choose where to save your `.csv` file locally (e.g., `nira_test_run.csv`). Click "Start Local Logging" to commence collecting. You can toggle this on and off without losing data.
*   **Parameters Panel:** Control settings like the Live Plot "Window Size" (how many samples look back in history) in real-time. Apply them to dynamically adjust the UI without disconnecting.
*   **Live Signals View:** Hardware-accelerated Matplotlib plotting rendering 100 Hz signals.
    *   **Top Plot:** `CH1` and `CH4` baseline capacitance outputs.
    *   **Bottom Plot:** The generated particle detection "Differential Signal".

## Option 2: Headless CLI Mode

For headless setups (like Raspberry Pi zero deployments) or scripting, the tool offers a `--cli` mode. This records the live USB output directly into your designated CSV without creating UI windows.

```bash
# Launch in CLI mode, specifying port and output file
python python/nira_dashboard.py --cli --port /dev/ttyUSB0 --baud 115200 --out test_01.csv
```

### CLI Output
The console will log debug connection messages and then begin streaming the converted particle detection strings:
`[DATA] ms:4219 | CH1:327 | CH4:255 | Diff:72 | Temp:25.0`

## Important Notes
- **Dependencies Dropback:** If you attempt to run the GUI mode but your Python environment lacks `tkinter` or `matplotlib`, the script will gracefully error-catch and fallback completely into **CLI Mode**.
- The dashboard is primarily meant to serve **v1.5 and newer** firmware. Please ensure your ESP32 is flashing the correct PlatformIO codebase.

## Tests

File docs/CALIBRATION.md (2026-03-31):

# Project Nira — Calibration & Zeroing Guide

## Why Calibration Matters

Project Nira measures *differential* capacitance. The absolute pF value
depends on electrode geometry, water conductivity, and temperature.
Only the *change from baseline* (`d0`–`d3`, `mp_index`) is meaningful.

## Baseline Capture Procedure

1. Fill sensor chamber with **clean, particle-free water** (distilled preferred)
2. Submerge electrodes fully — no air bubbles
3. Wait **30 seconds** for thermal and electrical stabilisation
4. Click **ZERO / BASELINE** in the GUI (or send `CMD:ZERO` via serial)
5. Firmware averages 32 readings per channel (~640 ms at 100 S/s)
6. GUI log shows: `zero_done base_pF: [xx.xx, xx.xx, xx.xx, xx.xx]`
7. All subsequent `d0`–`d3` and `mp_index` values are relative to this

## When to Re-Zero

- At the start of every measurement session
- After moving to a different water source
- After temperature change >5°C
- After device power cycle
- After replacing or repositioning electrodes

## Interpreting mp_index

| mp_index (pF RMS) | Interpretation |
|---|---|
| < 0.05 | Baseline noise — clean water |
| 0.05 – 0.10 | Slight perturbation — low particle count |
| > 0.10 | **Alert** — significant capacitive shift |
| > 0.30 | High particle load — verify with lab method |

These thresholds are empirical. Calibrate against known microplastic
concentrations for your specific electrode geometry and water chemistry.

## Field Notes

- Temperature coefficient: ~0.02 pF/°C — always re-zero after temp changes
- Bubbles on electrodes are the most common source of false positives
- 316L stainless is resistant to corrosion but wipe electrodes between samples

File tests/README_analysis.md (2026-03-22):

# Project Nira – GNU Octave Analysis

Sensor test analysis for the **Nira microplastic detection sensor**  
Device: `nira_esp32` | Measurement: `nira_sensor`  
by [only-foss](https://github.com/only-foss/Project-Nira)

---

## Test Conditions

| File | Condition | Samples |
|---|---|---|
| `test-0_cleanWater.csv` | Clean water (baseline) | 55 |
| `test-1_water_with_microplastics.csv` | Water with microplastics | 42 |

## Sensor Channels

| Field | Description |
|---|---|
| `ch1_raw` | Channel 1 – ADC raw reading |
| `ch4_raw` | Channel 4 – ADC raw reading |
| `diff_c1_c4` | CH1 − CH4 differential (primary detection feature) |

Data exported from InfluxDB (annotated CSV format).

---

## Key Finding

The **differential signal `diff_c1_c4`** cleanly separates both conditions:

| Condition | Mean diff | Std |
|---|---|-----|
| Clean water | **−193.6 ADC** | 128.6 |
| Microplastics | **+377.8 ADC** | 69.9 |

- Shift: **+571 ADC units** (~4.4σ above clean baseline)
- Suggested detection threshold: **~92 ADC units**
- Two-sample t-test: p << 0.001 (highly significant)

---

## Files

```
tests/
├── analysis/            ← run Octave from here
│   ├── nira_analysis.m
│   ├── nira_plot_*.m
│   ├── clean_water.csv
│   └── micro_water.csv
└── results/             ← auto-created, PNGs saved here
```

---

## How to Run

### Requirements
- [GNU Octave](https://octave.org/) ≥ 7.x  
  On Debian/Ubuntu: `sudo apt install octave`

```bash
cd tests/analysis
octave nira_analysis.m
```

Plots are saved to `tests/results/`.

---

## Preparing CSVs from InfluxDB Export

The raw InfluxDB annotated CSVs have 3 header rows. Convert them once with Python:

```python
import pandas as pd

for name, fname in [('clean_water', 'test-0_cleanWater.csv'),
                    ('micro_water',  'test-1_water_with_microplastics.csv')]:
    df = pd.read_csv(fname, skiprows=3)
    piv = df.pivot_table(index='_time', columns='_field',
                         values='_value', aggfunc='first').astype(float)
    piv.reset_index().to_csv(f'{name}.csv', index=False)
    print(f'Saved {name}.csv')
```

---

*Part of [Project Nira](https://github.com/only-foss/Project-Nira) — FOSS microplastic detection sensor.*

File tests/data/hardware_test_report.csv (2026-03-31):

ts | n | ch0 | ch1 | ch2 | ch3 | d0 | d1 | d2 | d3 | temp | bat_mv | mp_index | mode
76047 | 149 | 0.0005 | 0.0005 | 0.0005 | 0.0005 | 0.0000 | 0.0000 | 0.0000 | 0.0000 | 53.33 | 929 | 0.00000 | sample
76547 | 150 | 0.0005 | 0.0005 | 0.0005 | 0.0005 | 0.0000 | 0.0000 | 0.0000 | 0.0000 | 53.33 | 854 | 0.00000 | sample
77047 | 151 | 0.0005 | 0.0005 | 0.0005 | 0.0005 | 0.0000 | 0.0000 | 0.0000 | 0.0000 | 53.33 | 770 | 0.00000 | sample
77547 | 152 | 0.0005 | 0.0005 | 0.0005 | 0.0005 | 0.0000 | 0.0000 | 0.0000 | 0.0000 | 53.33 | 665 | 0.00000 | sample
78047 | 153 | 0.0005 | 0.0005 | 0.0005 | 0.0005 | 0.0000 | 0.0000 | 0.0000 | 0.0000 | 53.33 | 617 | 0.00000 | sample
78547 | 154 | 0.0005 | 0.0005 | 0.0005 | 0.0005 | 0.0000 | 0.0000 | 0.0000 | 0.0000 | 53.33 | 493 | 0.00000 | sample
79047 | 155 | 0.0005 | 0.0005 | 0.0005 | 0.0005 | 0.0000 | 0.0000 | 0.0000 | 0.0000 | 53.33 | 460 | 0.00000 | sample
79547 | 156 | 0.0005 | 0.0005 | 0.0005 | 0.0005 | 0.0000 | 0.0000 | 0.0000 | 0.0000 | 53.33 | 362 | 0.00000 | sample
80047 | 157 | 0.0005 | 0.0005 | 0.0005 | 0.0005 | 0.0000 | 0.0000 | 0.0000 | 0.0000 | 53.33 | 304 | 0.00000 | sample
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

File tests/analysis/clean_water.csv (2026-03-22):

_time | ch1_raw | ch4_raw | diff_c1_c4
2026-03-22T11:27:30Z | 8174.5 | 8400.75 | -226.25
2026-03-22T11:27:40Z | 8299.2 | 8329.2 | -30.0
2026-03-22T11:27:50Z | 8384.5 | 8611.75 | -227.25
2026-03-22T11:28:00Z | 8235.6 | 8469.6 | -234.0
2026-03-22T11:28:10Z | 8250.0 | 8303.4 | -53.4
2026-03-22T11:28:20Z | 8429.25 | 8464.75 | -35.5
2026-03-22T11:28:30Z | 8464.6 | 8487.0 | -22.4
2026-03-22T11:28:40Z | 8215.0 | 8422.6 | -207.6
2026-03-22T11:28:50Z | 8219.6 | 8364.4 | -144.8
2026-03-22T11:29:00Z | 8282.2 | 8458.0 | -175.8
2026-03-22T11:29:10Z | 8155.8 | 8504.6 | -348.8
2026-03-22T11:29:20Z | 8338.0 | 8635.25 | -297.25
2026-03-22T11:29:30Z | 8311.0 | 8412.0 | -101.0
2026-03-22T11:29:40Z | 8246.0 | 8501.2 | -255.2
2026-03-22T11:29:50Z | 8407.2 | 8465.4 | -58.2
2026-03-22T11:30:00Z | 8378.0 | 8446.25 | -68.25
2026-03-22T11:30:10Z | 8250.0 | 8362.6 | -112.6
2026-03-22T11:30:20Z | 8306.5 | 8354.5 | -48.0
2026-03-22T11:30:30Z | 8287.4 | 8409.0 | -121.6
2026-03-22T11:30:40Z | 8197.25 | 8386.25 | -189.0
2026-03-22T11:30:50Z | 8195.0 | 8443.4 | -248.4
2026-03-22T11:31:00Z | 8276.75 | 8328.25 | -51.5
2026-03-22T11:31:10Z | 8213.4 | 8334.8 | -121.4
2026-03-22T11:31:20Z | 8180.25 | 8503.75 | -323.5
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

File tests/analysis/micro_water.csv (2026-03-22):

_time | ch1_raw | ch4_raw | diff_c1_c4
2026-03-22T11:57:50Z | 8953.0 | 8605.0 | 348.0
2026-03-22T11:58:00Z | 8931.75 | 8543.5 | 388.25
2026-03-22T11:58:10Z | 8900.8 | 8563.2 | 337.6
2026-03-22T11:58:20Z | 8798.75 | 8424.5 | 374.25
2026-03-22T11:58:30Z | 8692.0 | 8328.4 | 363.6
2026-03-22T11:58:40Z | 8685.0 | 8311.0 | 374.0
2026-03-22T11:58:50Z | 8676.25 | 8427.0 | 249.25
2026-03-22T11:59:00Z | 8807.0 | 8620.8 | 186.2
2026-03-22T11:59:10Z | 8737.25 | 8386.5 | 350.75
2026-03-22T11:59:20Z | 8687.75 | 8299.25 | 388.5
2026-03-22T11:59:30Z | 8816.8 | 8407.8 | 409.0
2026-03-22T11:59:40Z | 8882.75 | 8470.0 | 412.75
2026-03-22T11:59:50Z | 8890.4 | 8562.0 | 328.4
2026-03-22T12:00:00Z | 8910.2 | 8491.0 | 419.2
2026-03-22T12:00:10Z | 8843.6 | 8525.4 | 318.2
2026-03-22T12:00:20Z | 8849.333333333334 | 8431.0 | 418.3333333333333
2026-03-22T12:00:30Z | 8878.5 | 8439.75 | 438.75
2026-03-22T12:00:40Z | 8949.4 | 8610.2 | 339.2
2026-03-22T12:00:50Z | 8894.6 | 8511.8 | 382.8
2026-03-22T12:01:00Z | 8852.333333333334 | 8395.333333333334 | 457.0
2026-03-22T12:01:10Z | 8876.6 | 8439.6 | 437.0
2026-03-22T12:01:20Z | 8963.25 | 8491.25 | 472.0
2026-03-22T12:01:30Z | 8972.0 | 8542.5 | 429.5
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

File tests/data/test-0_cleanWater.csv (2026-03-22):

#group | false | false | true | true | false | false | true | true | true | true
#datatype | string | long | dateTime:RFC3339 | dateTime:RFC3339 | dateTime:RFC3339 | double | string | string | string | string
#default | mean
 | result | table | _start | _stop | _time | _value | _field | _measurement | device | team
 |  | 0 | 2026-03-22T11:23:02.116340269Z | 2026-03-22T11:38:02.116340269Z | 2026-03-22T11:27:30Z | 8174.5 | ch1_raw | nira_sensor | nira_esp32 | domination
 |  | 0 | 2026-03-22T11:23:02.116340269Z | 2026-03-22T11:38:02.116340269Z | 2026-03-22T11:27:40Z | 8299.2 | ch1_raw | nira_sensor | nira_esp32 | domination
 |  | 0 | 2026-03-22T11:23:02.116340269Z | 2026-03-22T11:38:02.116340269Z | 2026-03-22T11:27:50Z | 8384.5 | ch1_raw | nira_sensor | nira_esp32 | domination
 |  | 0 | 2026-03-22T11:23:02.116340269Z | 2026-03-22T11:38:02.116340269Z | 2026-03-22T11:28:00Z | 8235.6 | ch1_raw | nira_sensor | nira_esp32 | domination
 |  | 0 | 2026-03-22T11:23:02.116340269Z | 2026-03-22T11:38:02.116340269Z | 2026-03-22T11:28:10Z | 8250 | ch1_raw | nira_sensor | nira_esp32 | domination
 |  | 0 | 2026-03-22T11:23:02.116340269Z | 2026-03-22T11:38:02.116340269Z | 2026-03-22T11:28:20Z | 8429.25 | ch1_raw | nira_sensor | nira_esp32 | domination
 |  | 0 | 2026-03-22T11:23:02.116340269Z | 2026-03-22T11:38:02.116340269Z | 2026-03-22T11:28:30Z | 8464.6 | ch1_raw | nira_sensor | nira_esp32 | domination
 |  | 0 | 2026-03-22T11:23:02.116340269Z | 2026-03-22T11:38:02.116340269Z | 2026-03-22T11:28:40Z | 8215 | ch1_raw | nira_sensor | nira_esp32 | domination
 |  | 0 | 2026-03-22T11:23:02.116340269Z | 2026-03-22T11:38:02.116340269Z | 2026-03-22T11:28:50Z | 8219.6 | ch1_raw | nira_sensor | nira_esp32 | domination
 |  | 0 | 2026-03-22T11:23:02.116340269Z | 2026-03-22T11:38:02.116340269Z | 2026-03-22T11:29:00Z | 8282.2 | ch1_raw | nira_sensor | nira_esp32 | domination
 |  | 0 | 2026-03-22T11:23:02.116340269Z | 2026-03-22T11:38:02.116340269Z | 2026-03-22T11:29:10Z | 8155.8 | ch1_raw | nira_sensor | nira_esp32 | domination
 |  | 0 | 2026-03-22T11:23:02.116340269Z | 2026-03-22T11:38:02.116340269Z | 2026-03-22T11:29:20Z | 8338 | ch1_raw | nira_sensor | nira_esp32 | domination
 |  | 0 | 2026-03-22T11:23:02.116340269Z | 2026-03-22T11:38:02.116340269Z | 2026-03-22T11:29:30Z | 8311 | ch1_raw | nira_sensor | nira_esp32 | domination
 |  | 0 | 2026-03-22T11:23:02.116340269Z | 2026-03-22T11:38:02.116340269Z | 2026-03-22T11:29:40Z | 8246 | ch1_raw | nira_sensor | nira_esp32 | domination
 |  | 0 | 2026-03-22T11:23:02.116340269Z | 2026-03-22T11:38:02.116340269Z | 2026-03-22T11:29:50Z | 8407.2 | ch1_raw | nira_sensor | nira_esp32 | domination
 |  | 0 | 2026-03-22T11:23:02.116340269Z | 2026-03-22T11:38:02.116340269Z | 2026-03-22T11:30:00Z | 8378 | ch1_raw | nira_sensor | nira_esp32 | domination
 |  | 0 | 2026-03-22T11:23:02.116340269Z | 2026-03-22T11:38:02.116340269Z | 2026-03-22T11:30:10Z | 8250 | ch1_raw | nira_sensor | nira_esp32 | domination
 |  | 0 | 2026-03-22T11:23:02.116340269Z | 2026-03-22T11:38:02.116340269Z | 2026-03-22T11:30:20Z | 8306.5 | ch1_raw | nira_sensor | nira_esp32 | domination
 |  | 0 | 2026-03-22T11:23:02.116340269Z | 2026-03-22T11:38:02.116340269Z | 2026-03-22T11:30:30Z | 8287.4 | ch1_raw | nira_sensor | nira_esp32 | domination
 |  | 0 | 2026-03-22T11:23:02.116340269Z | 2026-03-22T11:38:02.116340269Z | 2026-03-22T11:30:40Z | 8197.25 | ch1_raw | nira_sensor | nira_esp32 | domination
 |  | 0 | 2026-03-22T11:23:02.116340269Z | 2026-03-22T11:38:02.116340269Z | 2026-03-22T11:30:50Z | 8195 | ch1_raw | nira_sensor | nira_esp32 | domination
 |  | 0 | 2026-03-22T11:23:02.116340269Z | 2026-03-22T11:38:02.116340269Z | 2026-03-22T11:31:00Z | 8276.75 | ch1_raw | nira_sensor | nira_esp32 | domination
 |  | 0 | 2026-03-22T11:23:02.116340269Z | 2026-03-22T11:38:02.116340269Z | 2026-03-22T11:31:10Z | 8213.4 | ch1_raw | nira_sensor | nira_esp32 | domination
 |  | 0 | 2026-03-22T11:23:02.116340269Z | 2026-03-22T11:38:02.116340269Z | 2026-03-22T11:31:20Z | 8180.25 | ch1_raw | nira_sensor | nira_esp32 | domination
 |  | 0 | 2026-03-22T11:23:02.116340269Z | 2026-03-22T11:38:02.116340269Z | 2026-03-22T11:31:30Z | 8295.2 | ch1_raw | nira_sensor | nira_esp32 | domination
 |  | 0 | 2026-03-22T11:23:02.116340269Z | 2026-03-22T11:38:02.116340269Z | 2026-03-22T11:31:40Z | 8241.6 | ch1_raw | nira_sensor | nira_esp32 | domination
 |  | 0 | 2026-03-22T11:23:02.116340269Z | 2026-03-22T11:38:02.116340269Z | 2026-03-22T11:31:50Z | 8194 | ch1_raw | nira_sensor | nira_esp32 | domination
 |  | 0 | 2026-03-22T11:23:02.116340269Z | 2026-03-22T11:38:02.116340269Z | 2026-03-22T11:32:00Z | 8205.4 | ch1_raw | nira_sensor | nira_esp32 | domination
 |  | 0 | 2026-03-22T11:23:02.116340269Z | 2026-03-22T11:38:02.116340269Z | 2026-03-22T11:32:10Z | 8262.4 | ch1_raw | nira_sensor | nira_esp32 | domination
 |  | 0 | 2026-03-22T11:23:02.116340269Z | 2026-03-22T11:38:02.116340269Z | 2026-03-22T11:32:20Z | 8214.25 | ch1_raw | nira_sensor | nira_esp32 | domination
 |  | 0 | 2026-03-22T11:23:02.116340269Z | 2026-03-22T11:38:02.116340269Z | 2026-03-22T11:32:30Z | 8093.6 | ch1_raw | nira_sensor | nira_esp32 | domination
 |  | 0 | 2026-03-22T11:23:02.116340269Z | 2026-03-22T11:38:02.116340269Z | 2026-03-22T11:32:40Z | 8066 | ch1_raw | nira_sensor | nira_esp32 | domination
 |  | 0 | 2026-03-22T11:23:02.116340269Z | 2026-03-22T11:38:02.116340269Z | 2026-03-22T11:32:50Z | 7866.75 | ch1_raw | nira_sensor | nira_esp32 | domination
 |  | 0 | 2026-03-22T11:23:02.116340269Z | 2026-03-22T11:38:02.116340269Z | 2026-03-22T11:33:00Z | 8130.6 | ch1_raw | nira_sensor | nira_esp32 | domination
 |  | 0 | 2026-03-22T11:23:02.116340269Z | 2026-03-22T11:38:02.116340269Z | 2026-03-22T11:33:10Z | 8006.5 | ch1_raw | nira_sensor | nira_esp32 | domination
 |  | 0 | 2026-03-22T11:23:02.116340269Z | 2026-03-22T11:38:02.116340269Z | 2026-03-22T11:33:20Z | 8141.5 | ch1_raw | nira_sensor | nira_esp32 | domination
 |  | 0 | 2026-03-22T11:23:02.116340269Z | 2026-03-22T11:38:02.116340269Z | 2026-03-22T11:33:30Z | 8582.5 | ch1_raw | nira_sensor | nira_esp32 | domination
 |  | 0 | 2026-03-22T11:23:02.116340269Z | 2026-03-22T11:38:02.116340269Z | 2026-03-22T11:33:40Z | 8709.333333333334 | ch1_raw | nira_sensor | nira_esp32 | domination
 |  | 0 | 2026-03-22T11:23:02.116340269Z | 2026-03-22T11:38:02.116340269Z | 2026-03-22T11:33:50Z | 8517.333333333334 | ch1_raw | nira_sensor | nira_esp32 | domination
 |  | 0 | 2026-03-22T11:23:02.116340269Z | 2026-03-22T11:38:02.116340269Z | 2026-03-22T11:34:00Z | 8475 | ch1_raw | nira_sensor | nira_esp32 | domination
 |  | 0 | 2026-03-22T11:23:02.116340269Z | 2026-03-22T11:38:02.116340269Z | 2026-03-22T11:34:10Z | 8623.4 | ch1_raw | nira_sensor | nira_esp32 | domination
 |  | 0 | 2026-03-22T11:23:02.116340269Z | 2026-03-22T11:38:02.116340269Z | 2026-03-22T11:34:20Z | 8451.4 | ch1_raw | nira_sensor | nira_esp32 | domination
 |  | 0 | 2026-03-22T11:23:02.116340269Z | 2026-03-22T11:38:02.116340269Z | 2026-03-22T11:34:30Z | 8637.8 | ch1_raw | nira_sensor | nira_esp32 | domination
 |  | 0 | 2026-03-22T11:23:02.116340269Z | 2026-03-22T11:38:02.116340269Z | 2026-03-22T11:34:40Z | 8424.25 | ch1_raw | nira_sensor | nira_esp32 | domination
 |  | 0 | 2026-03-22T11:23:02.116340269Z | 2026-03-22T11:38:02.116340269Z | 2026-03-22T11:34:50Z | 8660.5 | ch1_raw | nira_sensor | nira_esp32 | domination
 |  | 0 | 2026-03-22T11:23:02.116340269Z | 2026-03-22T11:38:02.116340269Z | 2026-03-22T11:35:00Z | 8593.25 | ch1_raw | nira_sensor | nira_esp32 | domination
 |  | 0 | 2026-03-22T11:23:02.116340269Z | 2026-03-22T11:38:02.116340269Z | 2026-03-22T11:35:10Z | 8615.4 | ch1_raw | nira_sensor | nira_esp32 | domination
 |  | 0 | 2026-03-22T11:23:02.116340269Z | 2026-03-22T11:38:02.116340269Z | 2026-03-22T11:35:20Z | 8620.8 | ch1_raw | nira_sensor | nira_esp32 | domination
 |  | 0 | 2026-03-22T11:23:02.116340269Z | 2026-03-22T11:38:02.116340269Z | 2026-03-22T11:35:30Z | 8579 | ch1_raw | nira_sensor | nira_esp32 | domination
 |  | 0 | 2026-03-22T11:23:02.116340269Z | 2026-03-22T11:38:02.116340269Z | 2026-03-22T11:35:40Z | 8492 | ch1_raw | nira_sensor | nira_esp32 | domination
 |  | 0 | 2026-03-22T11:23:02.116340269Z | 2026-03-22T11:38:02.116340269Z | 2026-03-22T11:35:50Z | 8500 | ch1_raw | nira_sensor | nira_esp32 | domination
 |  | 0 | 2026-03-22T11:23:02.116340269Z | 2026-03-22T11:38:02.116340269Z | 2026-03-22T11:36:00Z | 8657 | ch1_raw | nira_sensor | nira_esp32 | domination
 |  | 0 | 2026-03-22T11:23:02.116340269Z | 2026-03-22T11:38:02.116340269Z | 2026-03-22T11:36:10Z | 8528.8 | ch1_raw | nira_sensor | nira_esp32 | domination
 |  | 0 | 2026-03-22T11:23:02.116340269Z | 2026-03-22T11:38:02.116340269Z | 2026-03-22T11:36:20Z | 8472 | ch1_raw | nira_sensor | nira_esp32 | domination
 |  | 0 | 2026-03-22T11:23:02.116340269Z | 2026-03-22T11:38:02.116340269Z | 2026-03-22T11:36:30Z | 8652 | ch1_raw | nira_sensor | nira_esp32 | domination
 |  | 1 | 2026-03-22T11:23:02.116340269Z | 2026-03-22T11:38:02.116340269Z | 2026-03-22T11:27:30Z | 8400.75 | ch4_raw | nira_sensor | nira_esp32 | domination
 |  | 1 | 2026-03-22T11:23:02.116340269Z | 2026-03-22T11:38:02.116340269Z | 2026-03-22T11:27:40Z | 8329.2 | ch4_raw | nira_sensor | nira_esp32 | domination
 |  | 1 | 2026-03-22T11:23:02.116340269Z | 2026-03-22T11:38:02.116340269Z | 2026-03-22T11:27:50Z | 8611.75 | ch4_raw | nira_sensor | nira_esp32 | domination
 |  | 1 | 2026-03-22T11:23:02.116340269Z | 2026-03-22T11:38:02.116340269Z | 2026-03-22T11:28:00Z | 8469.6 | ch4_raw | nira_sensor | nira_esp32 | domination
 |  | 1 | 2026-03-22T11:23:02.116340269Z | 2026-03-22T11:38:02.116340269Z | 2026-03-22T11:28:10Z | 8303.4 | ch4_raw | nira_sensor | nira_esp32 | domination
 |  | 1 | 2026-03-22T11:23:02.116340269Z | 2026-03-22T11:38:02.116340269Z | 2026-03-22T11:28:20Z | 8464.75 | ch4_raw | nira_sensor | nira_esp32 | domination
 |  | 1 | 2026-03-22T11:23:02.116340269Z | 2026-03-22T11:38:02.116340269Z | 2026-03-22T11:28:30Z | 8487 | ch4_raw | nira_sensor | nira_esp32 | domination
 |  | 1 | 2026-03-22T11:23:02.116340269Z | 2026-03-22T11:38:02.116340269Z | 2026-03-22T11:28:40Z | 8422.6 | ch4_raw | nira_sensor | nira_esp32 | domination
 |  | 1 | 2026-03-22T11:23:02.116340269Z | 2026-03-22T11:38:02.116340269Z | 2026-03-22T11:28:50Z | 8364.4 | ch4_raw | nira_sensor | nira_esp32 | domination
 |  | 1 | 2026-03-22T11:23:02.116340269Z | 2026-03-22T11:38:02.116340269Z | 2026-03-22T11:29:00Z | 8458 | ch4_raw | nira_sensor | nira_esp32 | domination
 |  | 1 | 2026-03-22T11:23:02.116340269Z | 2026-03-22T11:38:02.116340269Z | 2026-03-22T11:29:10Z | 8504.6 | ch4_raw | nira_sensor | nira_esp32 | domination
 |  | 1 | 2026-03-22T11:23:02.116340269Z | 2026-03-22T11:38:02.116340269Z | 2026-03-22T11:29:20Z | 8635.25 | ch4_raw | nira_sensor | nira_esp32 | domination
 |  | 1 | 2026-03-22T11:23:02.116340269Z | 2026-03-22T11:38:02.116340269Z | 2026-03-22T11:29:30Z | 8412 | ch4_raw | nira_sensor | nira_esp32 | domination
 |  | 1 | 2026-03-22T11:23:02.116340269Z | 2026-03-22T11:38:02.116340269Z | 2026-03-22T11:29:40Z | 8501.2 | ch4_raw | nira_sensor | nira_esp32 | domination
 |  | 1 | 2026-03-22T11:23:02.116340269Z | 2026-03-22T11:38:02.116340269Z | 2026-03-22T11:29:50Z | 8465.4 | ch4_raw | nira_sensor | nira_esp32 | domination
 |  | 1 | 2026-03-22T11:23:02.116340269Z | 2026-03-22T11:38:02.116340269Z | 2026-03-22T11:30:00Z | 8446.25 | ch4_raw | nira_sensor | nira_esp32 | domination
 |  | 1 | 2026-03-22T11:23:02.116340269Z | 2026-03-22T11:38:02.116340269Z | 2026-03-22T11:30:10Z | 8362.6 | ch4_raw | nira_sensor | nira_esp32 | domination
 |  | 1 | 2026-03-22T11:23:02.116340269Z | 2026-03-22T11:38:02.116340269Z | 2026-03-22T11:30:20Z | 8354.5 | ch4_raw | nira_sensor | nira_esp32 | domination
 |  | 1 | 2026-03-22T11:23:02.116340269Z | 2026-03-22T11:38:02.116340269Z | 2026-03-22T11:30:30Z | 8409 | ch4_raw | nira_sensor | nira_esp32 | domination
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

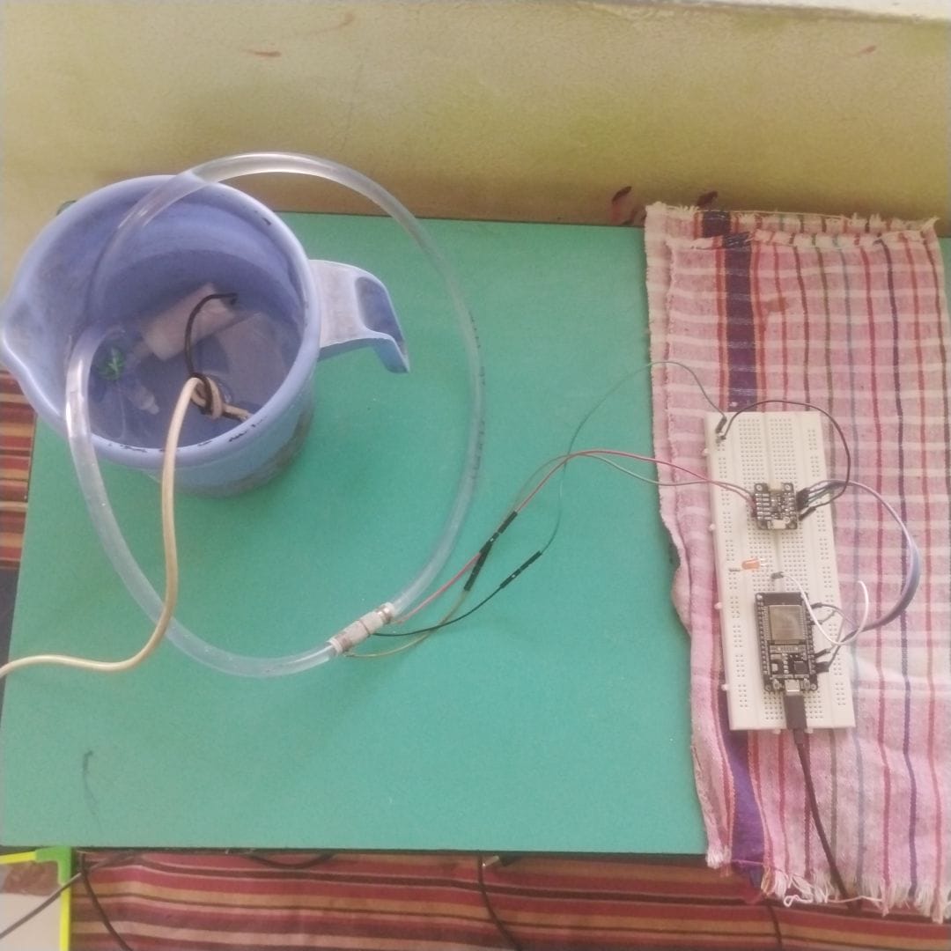
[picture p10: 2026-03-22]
tests/photos/v1.0-test-2.jpeg

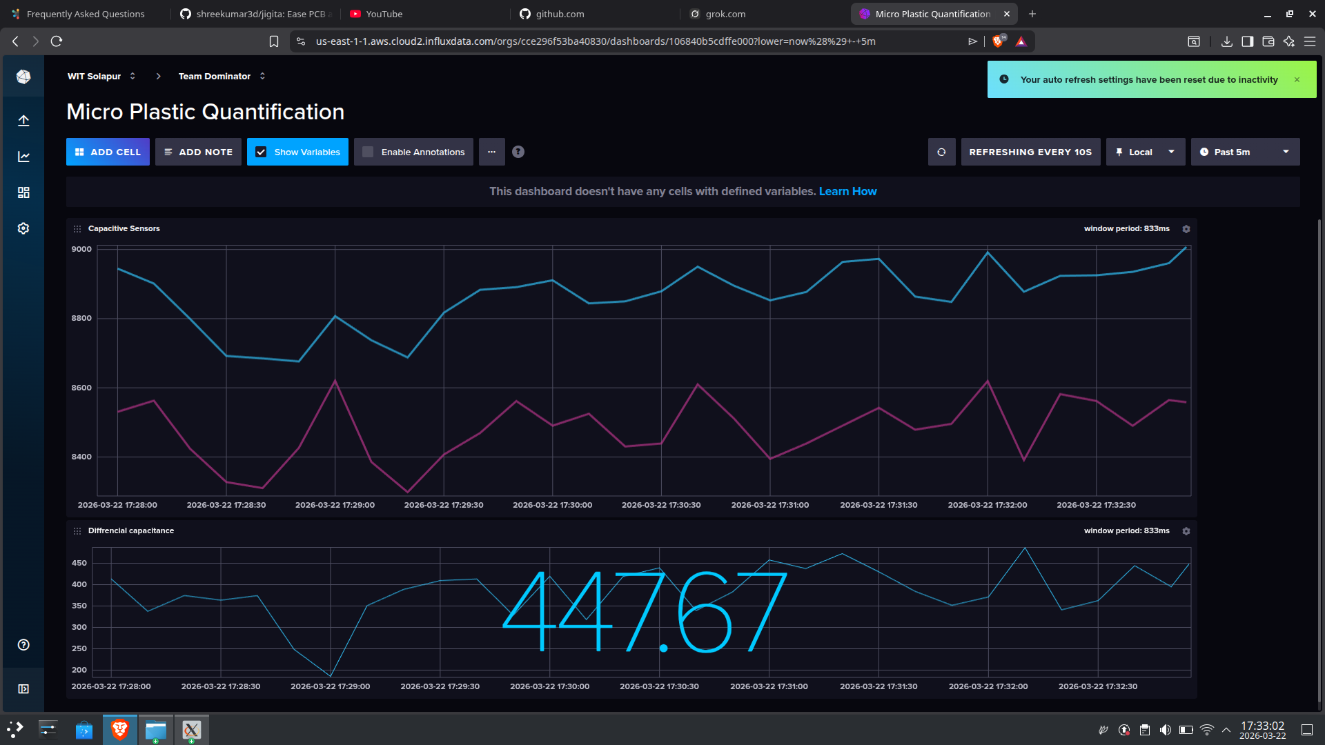
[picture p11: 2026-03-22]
tests/photos/test-1-water_with_microplastic-graph.png

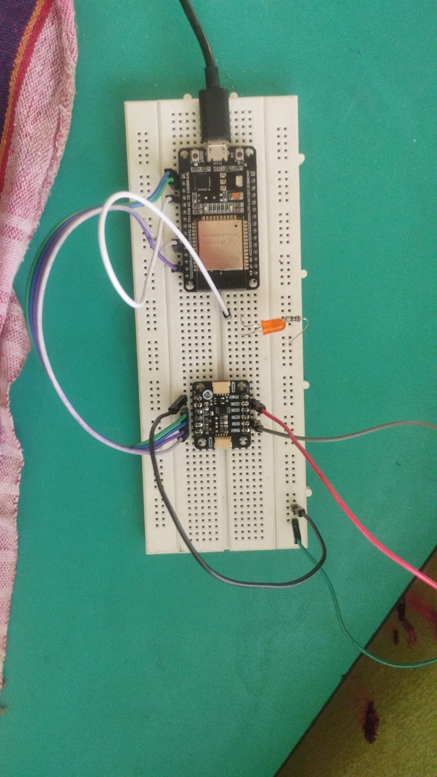
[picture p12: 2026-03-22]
tests/photos/v1.0-test.jpeg

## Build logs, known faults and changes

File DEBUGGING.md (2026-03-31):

# Project Nira — Debugging Guide (Local Serial USB)

This guide provides step-by-step instructions to validate and debug the serial data connection between the ESP32 hardware and the host PC Python tools. 

**Note:** This only covers the local direct USB serial setup.

## 1. Verify Hardware and PlatformIO Config
Ensure your `platformio.ini` has the correct settings for USB serial debugging:
```ini
build_flags = 
    -include Arduino.h
monitor_filters = default, esp32_exception_decoder, send_on_enter
monitor_speed = 115200
```
*Note: Make sure `-include Arduino.h` is present and monitor filters provide `send_on_enter` so you can send commands easily via the serial monitor.*

## 2. Compile and Upload Firmware
1. Open up the PlatformIO IDE.
2. Build the project to verify there are no compilation errors.
3. Upload the firmware to the ESP32 via USB.

## 3. Test Raw Serial JSON Output
Before running the Python scripts, test the raw ESP32 output using the PlatformIO Serial Monitor or any other basic serial monitor (like PuTTY or the Arduino IDE Serial Monitor window).

**Steps:**
1. Open PlatformIO Serial Monitor.
2. Reset the ESP32. You should see a boot message in valid JSON format:
   `{"status":"boot","fw":"nira-v1.1","proto":"nira-serial-v1"}`
3. You should then see:
   `{"status":"zeroing"}`
   followed shortly by:
   `{"status":"zero_done","base_pF":[0.0000,0.0000,0.0000,0.0000]}` (Values will vary)
   and finally:
   `{"status":"ready"}`
4. Send `CMD:START` followed by a newline (Enter key).
5. You should see a confirmation: `{"status":"streaming_start"}` and the continuous stream of JSON sensor readings at 500ms intervals by default.
6. The streaming frames must look exactly like this:
   `{"ts":1234567,"n":1,"ch0":12.34,"ch1":12.10,"ch2":11.98,"ch3":12.05,"d0":...}`
7. Send `CMD:STOP\n` to pause the stream.

**Common Error:** Non-JSON text appearing in the stream (e.g., `ch0:12.34 ch1:...`).
*Fix:* We have already removed the non-JSON `Serial.printf` logs from `main.cpp` targeting Arduino IDE plotters. If you see non-JSON lines, double check your `main.cpp` code to ensure all `Serial.printf()` loops are wrapping output inside proper JSON string formatting like `{"key":"value"}\n`.

## 4. Test Python Hardware Alignment via `hw_test.py`
To verify that the physical hardware completely aligns with the data analysis tests:
```bash
python3 tests/hw_test.py --port /dev/ttyUSB0 --baud 115200
```
*(Replace `/dev/ttyUSB0` with your actual port, e.g., `COM3` on Windows)*

The script will run 12 sequential tests including boot parsing, zeroing, command acknowledgements, timing, and parsing of 10 consecutive data frames.

**Common Error:** `JSONDecodeError` during data frame validation.
*Fix:* This denotes leftover debug strings being printed. Use the raw serial test (Step 3) to identify the offending lines.

## 5. View Data on Python Dashboard or GUI
Once `hw_test.py` reports `✅ PASS`, your hardware works correctly and produces valid parseable JSON.

Run the gui or dashboard tools to ensure everything is graphed and compiled normally:
```bash
python3 python/nira_gui.py --port /dev/ttyUSB0
```
This should launch an interface representing the channels dynamically without exceptions.

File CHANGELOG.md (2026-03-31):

# Changelog — Project Nira

All notable changes to this project will be documented here.
Format: [Keep a Changelog](https://keepachangelog.com/)
Versioning: [Semantic Versioning](https://semver.org/)

## [1.2.0] — 2026-03-31

### Added
- **Compliance**: Validated repo against FOSS Hack 2026 submission rules.
- **Reproducibility**: Added `setup.sh` (Linux/macOS) and `setup.bat` (Windows) for environment bootstrapping.
- **Documentation**: Updated README with technical usage and architecture overview.
- **License**: Confirmed MIT/CC BY-SA 4.0 dual-licensing for clarity.

### Changed
- Replaced non-FOSS libraries with open-source alternatives in `requirements.txt`.
- Refined project structure for better discoverability.

---
21: 
22: ## [1.1.0] — 2026-01-01

### Added
- Structured JSON serial output protocol (nira-serial-v1)
- `CMD:START`, `CMD:STOP`, `CMD:ZERO`, `CMD:RATE`, `CMD:RESET` command parser
- 32-sample baseline averaging (`capture_baseline()`)
- Microplastic index (`mp_index`) = RMS delta from baseline
- Battery voltage ADC readout (`bat_mv`)
- Internal temperature sensor readout (`temp`)
- Python real-time GUI (`software/nira_gui.py`)
- 5-panel live dashboard (raw pF, delta pF, MP index, temp, battery)
- One-click printable PDF/PNG report with statistics table
- One-click CSV data export
- Serial command control panel in GUI
- Alert system: amber highlight + sidebar warning when mp_index > 0.10
- `docs/SERIAL_PROTOCOL.md` — full protocol reference
- `docs/FIRMWARE_API.md` — firmware function reference
- `docs/GUI_USER_GUIDE.md` — end-user GUI guide
- `docs/CALIBRATION.md` — calibration and zeroing procedure
- `requirements.txt` — pinned Python dependencies
- `platformio.ini` — pinned PlatformIO build config
- `CONTRIBUTING.md`, GitHub issue templates

### Changed
- Firmware version bumped to nira-v1.1
- Serial output changed from ad-hoc prints to JSON protocol

## [1.0.0] — 2025-12-01

### Added
- Initial ESP32-S3 + FDC1004 firmware
- 4-channel capacitance reading
- Basic serial output
- KiCad schematics v1.0

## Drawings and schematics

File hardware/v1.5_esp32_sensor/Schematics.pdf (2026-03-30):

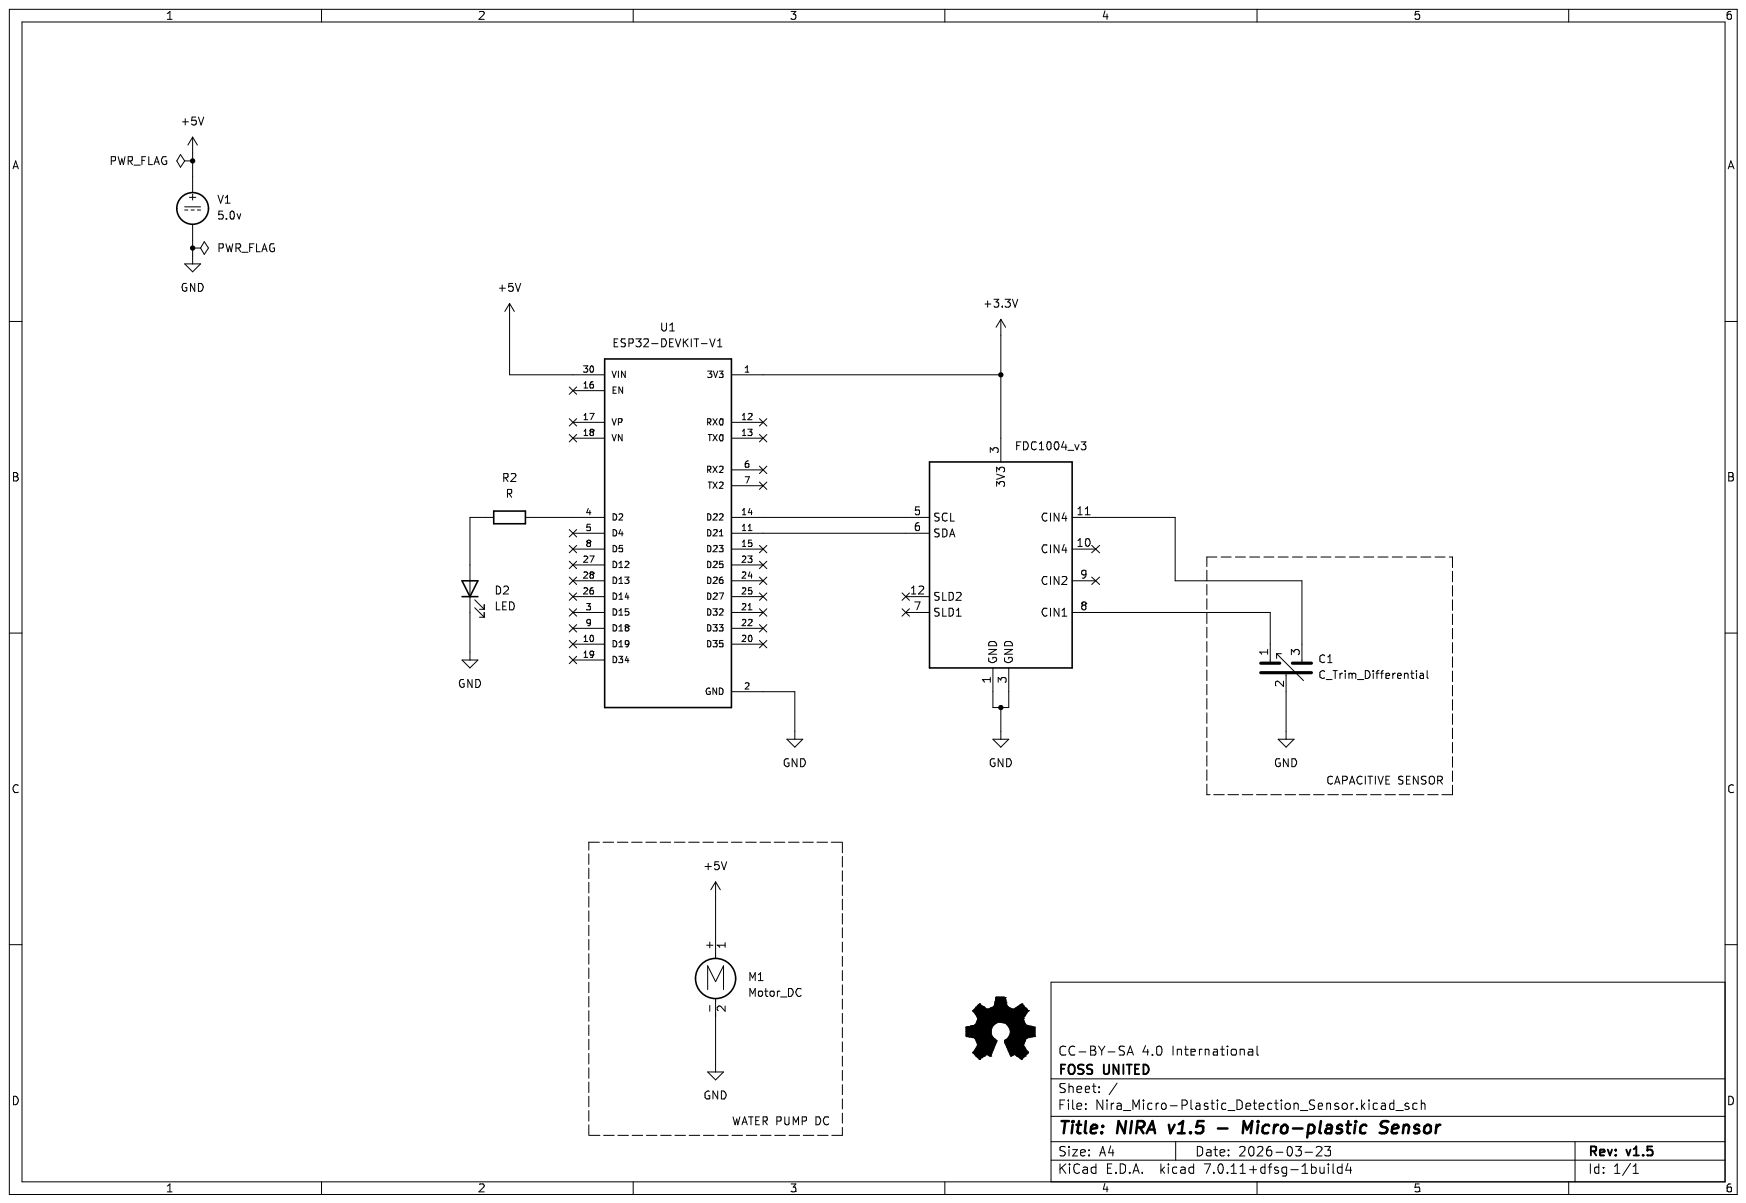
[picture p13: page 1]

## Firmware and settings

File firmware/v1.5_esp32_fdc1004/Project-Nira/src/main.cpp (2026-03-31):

// SPDX-License-Identifier: MIT
/**
 * @file main.cpp
 * @brief Project Nira — ESP32-S3 Firmware v1.1
 *
 * Reads capacitance/impedance data from the FDC1004 (or ADS131M08 ADC) and
 * streams structured JSON lines over USB-Serial at 115200 baud.
 *
 * Serial output protocol (one JSON object per line, newline-terminated):
 *   {"ts":1234567,"ch0":12.34,"ch1":12.10,"ch2":11.98,"ch3":12.05,
 *    "temp":28.5,"bat_mv":3820,"mode":"sample","mp_index":0.042}
 *
 * Control commands received over Serial (newline-terminated):
 *   CMD:ZERO          — re-zero / baseline capture
 *   CMD:START         — start streaming
 *   CMD:STOP          — pause streaming
 *   CMD:RATE:<n>      — set sample interval in ms (e.g. CMD:RATE:500)
 *   CMD:RESET         — software reset
 *
 * Hardware:
 *   ESP32-S3 + FDC1004 (I2C) + optional ADS131M08 (SPI)
 *   316L stainless electrodes, IP67 enclosure
 *
 * License: MIT
 * Project: https://github.com/only-foss/Project-Nira
 */

#include <Arduino.h>
#include <Wire.h>
#include <ArduinoJson.h>   // ArduinoJson v7 — add to platformio.ini: bblanchon/ArduinoJson

// ─── FDC1004 Register Map ────────────────────────────────────────────────────
#define FDC1004_ADDR        0x50
#define FDC1004_FDC_CONF    0x0C
#define FDC1004_MEAS1_MSB   0x00
#define FDC1004_MEAS2_MSB   0x02
#define FDC1004_MEAS3_MSB   0x04
#define FDC1004_MEAS4_MSB   0x06
#define FDC1004_CONF_CH1    0x08
#define FDC1004_CONF_CH2    0x09
#define FDC1004_CONF_CH3    0x0A
#define FDC1004_CONF_CH4    0x0B
#define FDC_CAP_DAC_DISABLED 0x1C00  // CAPDAC = 0, CHA = CHx, CHB = CAPDAC

// ─── Pin Definitions ─────────────────────────────────────────────────────────
#define I2C_SDA_PIN         21
#define I2C_SCL_PIN         22
#define LED_STATUS_PIN      2    // onboard LED
#define BAT_ADC_PIN         34   // battery voltage divider (adjust for your HW)

// ─── Configuration ───────────────────────────────────────────────────────────
#define SERIAL_BAUD         115200
#define DEFAULT_SAMPLE_MS   500   // default sample interval
#define BASELINE_SAMPLES    32    // samples averaged for zero baseline

// ─── Globals ─────────────────────────────────────────────────────────────────
static float   baseline_pF[4]  = {0.0f, 0.0f, 0.0f, 0.0f};
static bool    streaming        = true;
static uint32_t sample_interval = DEFAULT_SAMPLE_MS;
static uint32_t last_sample_ms  = 0;
static uint32_t sample_count    = 0;

// ─── FDC1004 Helpers ─────────────────────────────────────────────────────────

/**
 * @brief Write a 16-bit value to an FDC1004 register.
 */
static bool fdc_write16(uint8_t reg, uint16_t val) {
    Wire.beginTransmission(FDC1004_ADDR);
    Wire.write(reg);
    Wire.write((val >> 8) & 0xFF);
    Wire.write(val & 0xFF);
    return Wire.endTransmission() == 0;
}

/**
 * @brief Read a 32-bit measurement result from the FDC1004 (MSB + LSB regs).
 */
static int32_t fdc_read_meas(uint8_t msb_reg) {
    Wire.beginTransmission(FDC1004_ADDR);
    Wire.write(msb_reg);
    if (Wire.endTransmission(false) != 0) return 0;

    Wire.requestFrom((uint8_t)FDC1004_ADDR, (uint8_t)4);
    if (Wire.available() < 4) return 0;

    int32_t raw = ((int32_t)Wire.read() << 24)
                | ((int32_t)Wire.read() << 16)
                | ((int32_t)Wire.read() <<  8)
                |  (int32_t)Wire.read();
    return raw >> 8;  // 24-bit signed result
}

/**
 * @brief Convert raw FDC1004 24-bit signed value to picofarads.
 *        Full-scale = ±15 pF, 24-bit signed: 1 LSB = 30 pF / 2^24
 */
static float raw_to_pF(int32_t raw) {
    return (float)raw * (30.0f / (float)(1 << 24));
}

/**
 * @brief Configure all 4 FDC1004 channels for single-ended measurement.
 */
static void fdc_configure() {
    // MEAS1..4: CHA = CH1..4, CHB = CAPDAC, CAPDAC = 0
    fdc_write16(FDC1004_CONF_CH1, (0x00 << 13) | FDC_CAP_DAC_DISABLED);
    fdc_write16(FDC1004_CONF_CH2, (0x01 << 13) | FDC_CAP_DAC_DISABLED);
    fdc_write16(FDC1004_CONF_CH3, (0x02 << 13) | FDC_CAP_DAC_DISABLED);
    fdc_write16(FDC1004_CONF_CH4, (0x03 << 13) | FDC_CAP_DAC_DISABLED);
    // FDC_CONF: RATE=100S/s (01), REPEAT=1, MEAS1..4 enable
    fdc_write16(FDC1004_FDC_CONF, 0x0F9F);
    delay(20);
}

/**
 * @brief Trigger a single measurement cycle and read all 4 channels.
 * @param[out] pF  Array of 4 floats (pF per channel)
 */
static bool fdc_read_all(float pF[4]) {
    // Trigger single shot
    fdc_write16(FDC1004_FDC_CONF, 0x8F9F);
    delay(25);  // wait for conversion (100 S/s → ~10 ms, add margin)

    const uint8_t msb_regs[4] = {
        FDC1004_MEAS1_MSB, FDC1004_MEAS2_MSB,
        FDC1004_MEAS3_MSB, FDC1004_MEAS4_MSB
    };
    for (int i = 0; i < 4; i++) {
        int32_t raw = fdc_read_meas(msb_regs[i]);
        pF[i] = raw_to_pF(raw);
    }
    return true;
}

// ─── Sensor Utilities ────────────────────────────────────────────────────────

/**
 * @brief Read battery voltage in millivolts via ADC.
 *        Assumes 1:2 voltage divider, 3.3 V ref, 12-bit ADC.
 */
static uint32_t read_bat_mv() {
    uint32_t adc = analogRead(BAT_ADC_PIN);
    // (adc / 4095) * 3300 mV * 2 (divider)
    return (adc * 6600UL) / 4095UL;
}

/**
 * @brief Read die temperature from ESP32 internal sensor (approximate).
 */
static float read_temp_c() {
    // ESP32 has temperatureRead() in some frameworks; fallback to NaN
#ifdef __XTENSA__
    extern float temperatureRead();
    return temperatureRead();
#else
    return NAN;
#endif
}

/**
 * @brief Microplastic index: mean differential capacitance from baseline.
 *        Higher deviation → higher particle count proxy.
 */
static float compute_mp_index(float pF[4]) {
    float sum = 0.0f;
    for (int i = 0; i < 4; i++) {
        float delta = pF[i] - baseline_pF[i];
        sum += delta * delta;
    }
    // RMS deviation in pF
    return sqrtf(sum / 4.0f);
}

// ─── Baseline (Zero) Capture ─────────────────────────────────────────────────

/**
 * @brief Capture baseline by averaging BASELINE_SAMPLES readings.
 *        Called on startup and whenever CMD:ZERO is received.
 */
static void capture_baseline() {
    float accum[4] = {0};
    Serial.println("{\"status\":\"zeroing\"}");
    for (int s = 0; s < BASELINE_SAMPLES; s++) {
        float pF[4];
        if (fdc_read_all(pF)) {
            for (int i = 0; i < 4; i++) accum[i] += pF[i];
        }
        delay(20);
    }
    for (int i = 0; i < 4; i++) {
        baseline_pF[i] = accum[i] / BASELINE_SAMPLES;
    }
    Serial.printf("{\"status\":\"zero_done\","
                  "\"base_pF\":[%.4f,%.4f,%.4f,%.4f]}\n",
                  baseline_pF[0], baseline_pF[1],
                  baseline_pF[2], baseline_pF[3]);
}

// ─── Command Parser ───────────────────────────────────────────────────────────

/**
 * @brief Parse and execute a command string received over Serial.
 * @param cmd  Null-terminated command string (leading/trailing whitespace OK).
 */
static void handle_command(const char* cmd) {
    if (strncmp(cmd, "CMD:ZERO", 8) == 0) {
        capture_baseline();
    } else if (strncmp(cmd, "CMD:START", 9) == 0) {
        streaming = true;
        Serial.println("{\"status\":\"streaming_start\"}");
    } else if (strncmp(cmd, "CMD:STOP", 8) == 0) {
        streaming = false;
        Serial.println("{\"status\":\"streaming_stop\"}");
    } else if (strncmp(cmd, "CMD:RESET", 9) == 0) {
        Serial.println("{\"status\":\"resetting\"}");
        delay(100);
        ESP.restart();
    } else if (strncmp(cmd, "CMD:RATE:", 9) == 0) {
        int ms = atoi(cmd + 9);
        if (ms >= 50 && ms <= 60000) {
            sample_interval = (uint32_t)ms;
            Serial.printf("{\"status\":\"rate_set\",\"interval_ms\":%u}\n",
                          sample_interval);
        } else {
            Serial.println("{\"error\":\"invalid_rate\"}");
        }
    } else {
        Serial.printf("{\"error\":\"unknown_cmd\",\"cmd\":\"%s\"}\n", cmd);
    }
}

// ─── Arduino Entry Points ─────────────────────────────────────────────────────

void setup() {
    Serial.begin(SERIAL_BAUD);
    while (!Serial) delay(10);

    pinMode(LED_STATUS_PIN, OUTPUT);
    analogReadResolution(12);

    Wire.begin(I2C_SDA_PIN, I2C_SCL_PIN);
    Wire.setClock(400000);  // 400 kHz I2C

    // Announce firmware version
    Serial.println("{\"status\":\"boot\",\"fw\":\"nira-v1.1\","
                   "\"proto\":\"nira-serial-v1\"}");

    fdc_configure();
    capture_baseline();

    Serial.println("{\"status\":\"ready\"}");
    last_sample_ms = millis();
}

void loop() {
    // ── Handle incoming serial commands ──────────────────────────────────────
    if (Serial.available()) {
        static char cmd_buf[64];
        static uint8_t cmd_len = 0;
        char c = Serial.read();
        if (c == '\n' || c == '\r') {
            if (cmd_len > 0) {
                cmd_buf[cmd_len] = '\0';
                handle_command(cmd_buf);
                cmd_len = 0;
            }
        } else if (cmd_len < sizeof(cmd_buf) - 1) {
            cmd_buf[cmd_len++] = c;
        }
    }

    // ── Periodic sensor sampling ──────────────────────────────────────────────
    uint32_t now = millis();
    if (streaming && (now - last_sample_ms >= sample_interval)) {
        last_sample_ms = now;

        float pF[4];
        if (!fdc_read_all(pF)) {
            Serial.println("{\"error\":\"sensor_read_failed\"}");
            digitalWrite(LED_STATUS_PIN, LOW);
            return;
        }

        float mp_index = compute_mp_index(pF);
        float temp     = read_temp_c();
        uint32_t bat   = read_bat_mv();

        // ── Emit JSON sample line ─────────────────────────────────────────────
        // Format: single line, newline-terminated — easy for Python readline()
        Serial.printf(
            "{\"ts\":%lu,\"n\":%lu,"
            "\"ch0\":%.4f,\"ch1\":%.4f,\"ch2\":%.4f,\"ch3\":%.4f,"
            "\"d0\":%.4f,\"d1\":%.4f,\"d2\":%.4f,\"d3\":%.4f,"
            "\"temp\":%.2f,\"bat_mv\":%lu,\"mp_index\":%.5f,"
            "\"mode\":\"sample\"}\n",
            (unsigned long)now,
            (unsigned long)++sample_count,
            pF[0], pF[1], pF[2], pF[3],
            pF[0] - baseline_pF[0],
            pF[1] - baseline_pF[1],
            pF[2] - baseline_pF[2],
            pF[3] - baseline_pF[3],
            isnan(temp) ? -99.0f : temp,
            (unsigned long)bat,
            mp_index
        );

        // Blink LED on each sample
        digitalWrite(LED_STATUS_PIN, HIGH);
        delay(5);
        digitalWrite(LED_STATUS_PIN, LOW);
    }
}

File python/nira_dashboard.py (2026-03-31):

#!/usr/bin/env python3
# SPDX-License-Identifier: MIT
# Copyright (C) 2026  only-foss
"""
Project Nira — Dashboard & Live Serial Logger
Provides a full GUI Dashboard (Live Plots, CSV logging, Parameters) 
and a CLI mode for headless operation.
"""

import sys
import csv
import time
import argparse
import threading
import typing
import serial
import serial.tools.list_ports
import os
from collections import deque

def run_cli_mode(port, baud, outfile):
    """Headless CLI mode for serial logging"""
    print(f"--- Nira CLI Mode ---")
    print(f"Connecting to {port} at {baud} baud...")
    try:
        ser = serial.Serial(port, baud, timeout=1)
    except Exception as e:
        print(f"Error opening {port}: {e}")
        return

    print(f"Logging to {outfile} (Press Ctrl+C to stop)")
    with open(outfile, mode='a', newline='') as f:
        writer = csv.writer(f)
        f.seek(0, 2)
        if f.tell() == 0:
            writer.writerow(["time_ms", "CH1_raw", "CH4_raw", "Diff_C1_C4", "Temp_C"])
        
        try:
            while True:
                if ser.in_waiting > 0:
                    line = ser.readline().decode('utf-8', errors='ignore').strip()
                    if "time_ms" in line or "Sensor ready" in line or "WiFi" in line:
                        print(f"[DEBUG] {line}")
                        continue
                    
                    parts = line.split(',')
                    if len(parts) == 5:
                        writer.writerow(parts)
                        f.flush()
                        print(f"[DATA] ms:{parts[0]} | CH1:{parts[1]} | CH4:{parts[2]} | Diff:{parts[3]} | Temp:{parts[4]}")
        except KeyboardInterrupt:
            print("\nStopped.")
        finally:
            ser.close()

def run_gui_mode(default_port, default_baud, default_out):
    """Full GUI Dashboard using Tkinter and Matplotlib"""
    import tkinter as tk
    from tkinter import ttk, messagebox, filedialog
    import matplotlib
    matplotlib.use("TkAgg")
    from matplotlib.backends.backend_tkagg import FigureCanvasTkAgg
    from matplotlib.figure import Figure
    import matplotlib.animation as animation

    class NiraDashboard(tk.Tk):
        # type hints
        serial_conn: typing.Any
        fig: typing.Any
        ax1: typing.Any
        ax2: typing.Any
        canvas: typing.Any
        port_var: typing.Any
        baud_var: typing.Any
        file_var: typing.Any
        window_var: typing.Any
        interval_var: typing.Any
        port_cb: typing.Any
        connect_btn: typing.Any
        log_btn: typing.Any
        status_bar: typing.Any
        idx: int
        
        def __init__(self):
            super().__init__()
            self.title("Project Nira — Live Data Dashboard")
            self.geometry("1100x750")
            
            # --- State Variables ---
            self.serial_conn = None
            self.is_logging = False
            self.out_file = default_out
            self.max_pts = 512
            self.update_interval = 100
            
            # Data Queues
            self.t_data = deque(maxlen=self.max_pts)
            self.ch1_data = deque(maxlen=self.max_pts)
            self.ch4_data = deque(maxlen=self.max_pts)
            self.diff_data = deque(maxlen=self.max_pts)
            
            self.build_ui()
            
            # Start background serial read thread
            self.read_thread = threading.Thread(target=self.serial_read_loop, daemon=True)
            self.read_thread.start()
            
            # # Matplotlib Animation
            # self.anim = animation.FuncAnimation(self.fig, self.update_plot, interval=100, blit=False)
            self.anim = animation.FuncAnimation(self.fig, self.update_plot, interval=100, blit=False, cache_frame_data=False)

        def build_ui(self):
            # --- NEW / FIXED: Status Bar at Bottom ---
            self.status_bar = tk.Label(self, text="NOT READY (Stopped / Zeroing)", bg="red", fg="white", font=("Helvetica", 16, "bold"), pady=15)
            self.status_bar.pack(side=tk.BOTTOM, fill=tk.X)

            # Left Panel: Controls
            control_frame = ttk.Frame(self, width=320, padding=10)
            control_frame.pack(side=tk.LEFT, fill=tk.Y)
            control_frame.pack_propagate(False)

            # 1. Connection Frame
            conn_lf = ttk.LabelFrame(control_frame, text="Connection")
            conn_lf.pack(fill=tk.X, pady=5)
            
            ttk.Label(conn_lf, text="Port:").grid(row=0, column=0, sticky=tk.W, padx=2, pady=2)
            self.port_var = tk.StringVar(value=default_port)
            self.port_cb = ttk.Combobox(conn_lf, textvariable=self.port_var, width=15)
            self.port_cb.grid(row=0, column=1, padx=2, pady=2)
            ttk.Button(conn_lf, text="↻", width=3, command=self.refresh_ports).grid(row=0, column=2, padx=2, pady=2)
            self.refresh_ports()
            
            ttk.Label(conn_lf, text="Baud:").grid(row=1, column=0, sticky=tk.W, padx=2, pady=2)
            self.baud_var = tk.StringVar(value=str(default_baud))
            ttk.Combobox(conn_lf, textvariable=self.baud_var, values=["9600", "115200", "460800"], width=15).grid(row=1, column=1, padx=2, pady=2)
            
            self.connect_btn = ttk.Button(conn_lf, text="Connect", command=self.toggle_connection)
            self.connect_btn.grid(row=2, column=0, columnspan=3, sticky=tk.EW, padx=2, pady=5)
            
            # 2. Device Controls Frame --- NEW / FIXED: Device control buttons ---
            dev_lf = ttk.LabelFrame(control_frame, text="Device Controls")
            dev_lf.pack(fill=tk.X, pady=5)
            btn_frame = ttk.Frame(dev_lf)
            btn_frame.pack(fill=tk.X, pady=2)
            ttk.Button(btn_frame, text="Start", command=lambda: self.send_command("start\n")).pack(side=tk.LEFT, expand=True, fill=tk.X, padx=1)
            ttk.Button(btn_frame, text="Stop", command=lambda: self.send_command("stop\n")).pack(side=tk.LEFT, expand=True, fill=tk.X, padx=1)
            ttk.Button(btn_frame, text="Zero", command=lambda: self.send_command("zero\n")).pack(side=tk.LEFT, expand=True, fill=tk.X, padx=1)
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

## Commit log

2026-03-13 Added .gitignore to hardware kicad build files
2026-03-13 esp32 firmware - 100hz sampling
2026-03-14 Kicad schematics added for capacitive method
    [Nira_Micro-Plastic_Detection_Sensor.kicad_pcb, Nira_Micro-Plastic_Detection_Sensor.kicad_sch]
2026-03-14 kicad_project backup removed
2026-03-14 schematics pdf added
    [Nira_Micro-Plastic_Detection_Sensor.kicad_sch]
2026-03-14 software licencce added and hardware licence updated
    [Nira_Micro-Plastic_Detection_Sensor.kicad_sch]
2026-03-15 database switched to foss provider
2026-03-15 schematic updated andhw and sw version mismatch fixed
    [nira_esp32.ino]
2026-03-15 LED protection resistor added
    [Nira_Micro-Plastic_Detection_Sensor.csv, Nira_Micro-Plastic_Detection_Sensor.kicad_sch]
2026-03-22 tested with baseline(clear-water) and test-sample (microplastic-HDPE) and .csv output recorded from DB
    [test-0_cleanWater.csv, test-1_water_with_microplastics.csv]
2026-03-22 test data imported and visulaised using GUN Octave
    [Nira_Micro-Plastic_Detection_Sensor.kicad_sch, clean_water.csv, micro_water.csv]
2026-03-22 organised testdata test result
    [BOM.csv, Nira_Micro-Plastic_Detection_Sensor.csv, clean_water.csv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]
2026-03-22 remove lck files from kicad
2026-03-23 chore: gitignore KiCad backup zips
2026-03-23 docs: complete OSHW documentation v1.0
    [ESP32-DEVKIT-V1.step, ESP32-DEVKIT-V258.step, Nira_Micro-Plastic_Detection_Sensor.csv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]
2026-03-23 chore: fix language detection - Octave not MATLAB, hide KiCad files
2026-03-23 chore: fix language detection — Octave not MATLAB, hide KiCad and CSV
2026-03-23 chore: fix language detection — Octave not MATLAB, vendor non-code files
2026-03-23 chore: show all languages — Octave, Arduino, KiCad
2026-03-23 Circuit Digram Illustration added from Draw.io
2026-03-25 switched to platformio ini
2026-03-26 docs: fdc1004 module rendered in circuit illustration
2026-03-26 Update README.md
    fixed stage from deployment to experimentation to comply credibility, as it is not lab proven yet
2026-03-27 fix: improve language detection in .gitattributes
    - Force *.ino and *.cpp as C++
    - Mark *.m as MATLAB/Octave
    - Mark generated KiCad files as linguist-generated
    - Set binary files correctly
2026-03-30 docs: standardize versions to v1.5 everywhere and generate Wiki structure
    [BOM.csv, ESP32-DEVKIT-V1.step, ESP32-DEVKIT-V258.step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]
2026-03-30 feat: revert firmware SD logging to align with hardware v1.5 schematic, add real-time serial logger
    [main.cpp]
2026-03-30 docs: add circuit diagram and update dashboard usage in USAGE.md
2026-03-30 docs: update README text and add full Breadboard WIRING_NOTES.md
2026-03-30 feat/docs: resolves #10 (secrets.h auth loop) and resolves #12 (Mermaid architecture diagram)
    [main.cpp]
2026-03-30 fix: resolve pylance linting errors
    [nira_dashboard.py]
2026-03-31 feat: add ArduinoJson dependency, project documentation, and environment setup scripts
    [hardware_test_report.csv, nira_data_local.csv]
2026-03-31 automated scaling added & firmware upload added
    [nira_data_local.csv]
2026-03-31 auto flash
    [nira_data_local.csv]
